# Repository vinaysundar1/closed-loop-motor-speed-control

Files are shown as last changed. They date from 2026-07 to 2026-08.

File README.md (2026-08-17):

# PID Motor Speed Controller

Closed-loop DC motor speed control using a quadrature encoder for feedback and a PID
algorithm to hold a target RPM, running on an Arduino Uno. Includes real-time serial
plotting and an OLED status display.

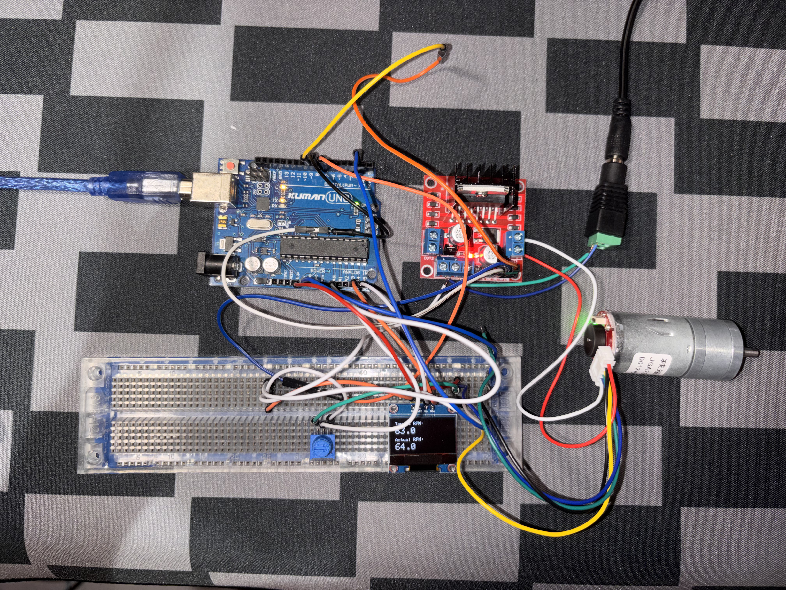
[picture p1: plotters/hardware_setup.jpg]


*Arduino Uno, L298N motor driver, GA25-370 encoder motor, potentiometer, and OLED display with a live RPM readout shown on screen.*

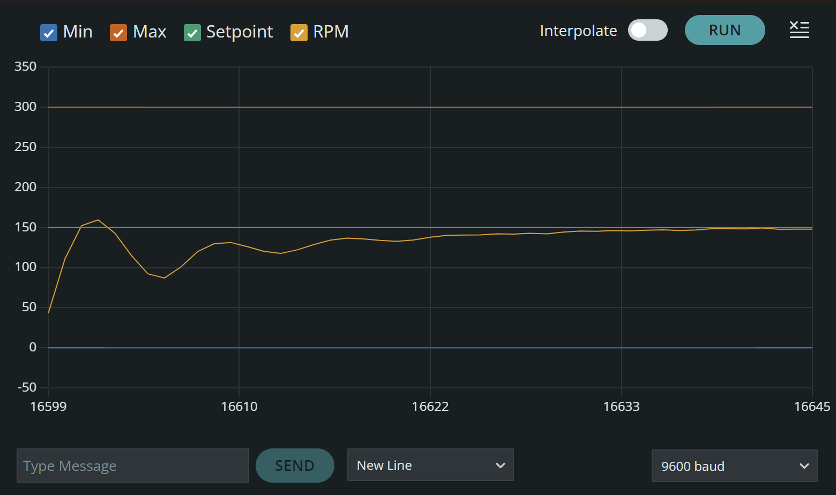
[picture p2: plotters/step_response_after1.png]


*Kp=0.5, Ki=0.5, Kd=0.08 — settles within one overshoot/undershoot cycle (~157 RPM
peak, ~90 RPM trough) and holds steady at setpoint.*

## Results

With a live, continuously-varying setpoint (driven by a potentiometer rather than a
fixed step), the controller tracks a ramping target with **one damped
overshoot/undershoot cycle** before settling, and holds within roughly **±2 RPM of
setpoint at steady state**.

## Hardware

| Component | Details |
|---|---|
| Arduino Uno | Microcontroller |
| L298N H-Bridge | Motor driver |
| DC motor with rotary encoder | GA25-370, 12V, 500 RPM nominal |
| 0.96" OLED display (SSD1306) | I2C status display |
| 10K potentiometer | Setpoint dial |
| 12V power supply or battery pack | Motor power |
| Breadboard + jumper wires | — |

## System Block Diagram

```mermaid
flowchart LR
    P[Potentiometer<br/>Setpoint Dial] -->|analog read,<br/>mapped 0-400 RPM| A[Setpoint]
    A --> B((Sum))
    F[Encoder Feedback] --> B
    B -->|error| C[PID Controller]
    C -->|PWM 0-255| D[Motor Driver / H-Bridge]
    D --> E[DC Gear Motor]
    E -->|shaft rotation| F
    E --> G[OLED Display]
    A --> G
```

## How It Works

1. **Speed measurement:** A hardware interrupt counts encoder pulses on every rising
   edge. Every 100 ms, the tick count is converted to RPM:
   `RPM = (ticks / PPR) * (60000 / interval_ms)`
2. **Noise filtering:** Raw RPM is smoothed with an exponential moving average (EMA)
   before being used anywhere else in the loop, since tick-count-based measurement
   over a short window is inherently noisy.
3. **PID calculation:** Standard proportional + integral + derivative sum, with:
   - A second EMA filter applied specifically to the derivative term (derivative
     amplifies noise more than any other term).
   - Conditional-integration anti-windup — the integral only accumulates when doing
     so wouldn't push the output past the PWM actuator limits (0–255).
4. **Actuation:** Final PID output is clamped to 0–255 (the PID math itself has no
   upper or lower bound, but `analogWrite` only accepts an 8-bit PWM duty cycle, so
   the raw sum has to be forced into the range the hardware can actually accept) and
   written via `analogWrite` to the motor driver's PWM input.

## Tuning Process

**Initial attempt** — naive PID with unfiltered RPM feedback:

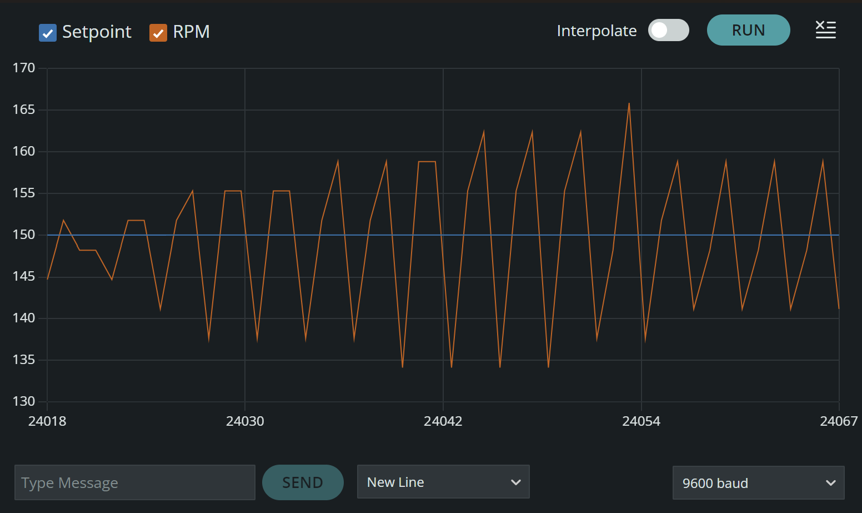
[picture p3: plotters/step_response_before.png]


*Kp=0.6, Ki=0.1, Kd=0.05 — oscillation amplitude grows over time rather than settling*

Diagnosis: the derivative term was amplifying tick-count measurement noise (division
by a small `dt` multiplies noise), and the integral anti-windup only clamped the
final value rather than preventing over-accumulation during saturation, both
contributing to a sustained/growing limit cycle.

**Fix:** added EMA filtering on the RPM measurement and on the derivative term, and
switched to conditional-integration anti-windup.

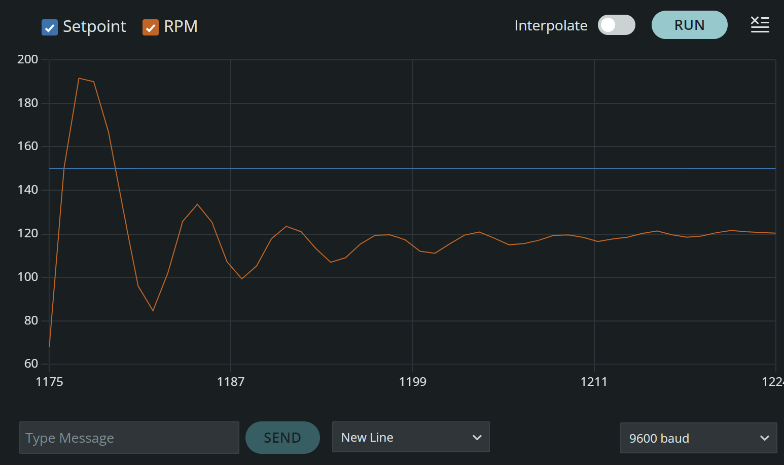
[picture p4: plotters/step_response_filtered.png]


*Kp=1.0, Ki=0.08, Kd=0.02 — clean damped response, but settles ~30 RPM below setpoint*

Diagnosis: proportional control alone cannot fully close steady-state error against
real motor friction/load, that gap can only be closed by the integral term, and Ki
was too small to close it in a reasonable time.

**Increased Ki to close the steady-state gap:**

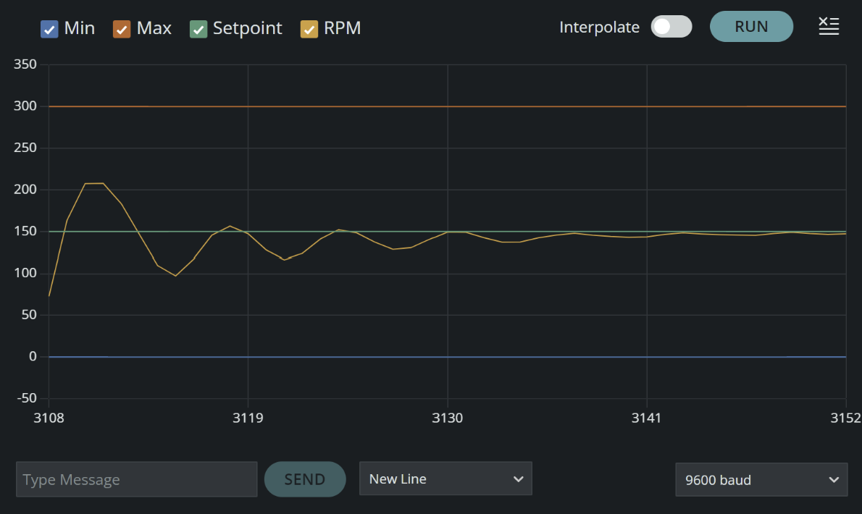
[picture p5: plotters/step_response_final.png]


*Kp=1.0, Ki=0.75, Kd=0.02 — closes the steady-state gap, but rings through roughly two
decaying overshoot/undershoot cycles before settling*

**Isolating the double-oscillation:** to find the cause, Kp was held fixed at 1.0
while Ki and Kd were varied independently across several tests (Ki: 0.75 → 0.35 → 0.5;
Kd: 0.02 → 0.2 → 0.08). The first overshoot peak stayed essentially unchanged
(~205–233 RPM) across every one of these combinations — strong evidence that Kp, not
Ki or Kd, was driving the size of that first overshoot, since neither term had moved
it despite multiple independent tests.

**Note on Ki tuning:** I also tested higher Ki values (up to 1.0) to see if faster settling was worth the tradeoff. Higher Ki consistently reduced settling time but increased overshoot (up to ~172 RPM vs. the original ~157 RPM), and increasing Kd alongside it didn't meaningfully reduce that overshoot. I kept Kp=0.5, Ki=0.5, Kd=0.08 as the final configuration since it produced the smallest overshoot/undershoot swings, which I prioritized over faster settling for this system.

**Final tune:** lowered Kp itself (1.0 → 0.6 → 0.5), keeping Ki=0.5 and Kd=0.08 fixed.
The first overshoot dropped sharply with each reduction (≈205 → 170 → 157 RPM), while
the undershoot depth stayed roughly constant (~90–100 RPM) regardless of Kp.



*Kp=0.5, Ki=0.5, Kd=0.08 — settles after one overshoot/undershoot cycle (~157 RPM peak,
~90 RPM trough), then a smooth, non-oscillatory approach to setpoint*

## Live Setpoint via Potentiometer

The initial tuning above used a fixed, hardcoded setpoint (150 RPM) for a clean,
repeatable step-response test. Once the gains were validated, the setpoint was
switched to a potentiometer read on an analog pin, mapped to a 0–400 RPM range, so
the target speed can be changed live by turning a knob.

A moving setpoint introduces failure modes a fixed step test doesn't expose:

- **Small electrical noise on the analog reading** caused the setpoint to
  flicker by a couple RPM every loop, which would look like a disturbance to the
  derivative term. Fixed with a deadband: the setpoint only updates if the
  new reading differs from the current one by more than 3 RPM.

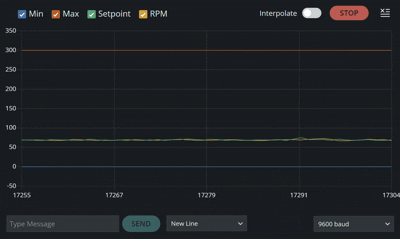
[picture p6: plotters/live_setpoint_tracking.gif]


*Kp=0.5, Ki=0.5, Kd=0.08 — RPM (orange) tracks a setpoint (green) jump, with one overshoot to one undershoot before settling and
holding steady-state tracking at the new target*

## Final PID Gains

| Gain | Value | Purpose |
|---|---|---|
| Kp | 0.5 | Primary response to instantaneous error; lowered from an initial 1.0 after isolating it as the driver of first-overshoot magnitude |
| Ki | 0.5 | Eliminates steady-state error from motor friction/load |
| Kd | 0.08 | Damps overshoot; raised from an initial 0.02 now that the derivative acts on a filtered signal |

## PCB Design

The breadboard prototype above was translated into a custom PCB in KiCad,
consolidating the Arduino, motor driver, and peripheral connections into a single
soldered board with defined connector headers.

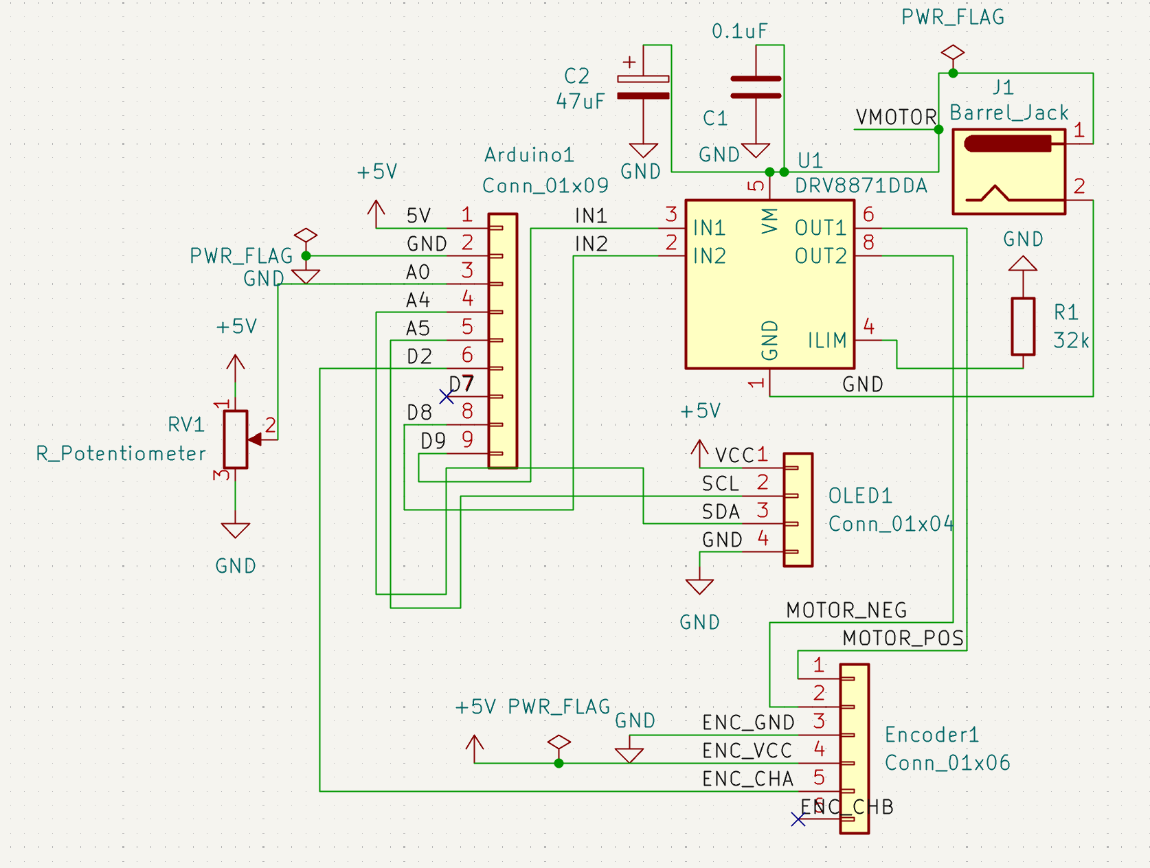
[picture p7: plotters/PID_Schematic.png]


*Full schematic — Arduino header, DRV8871 motor driver with support circuitry,
barrel jack power input, and connector headers for the encoder, OLED, and
potentiometer.*

### Driver Selection: DRV8871 over L298N

The original L298N module (used in the breadboard build above) was replaced with a
TI DRV8871 integrated H-bridge driver on the custom PCB. The DRV8871 integrates current limiting and thermal
protection directly, at the cost of requiring board-level component selection
(current-limit resistor, decoupling) rather than a plug-and-play module.

### Current-Limit (ILIM) Resistor

The DRV8871 sets its current limit via a resistor from ILIM to GND, per the
datasheet relationship ITRIP ≈ 64,000 / R_ILIM(Ω). The GA25-370's rated block/stall
current is 1.1A; a 32kΩ resistor was chosen to set a ~2A limit, giving roughly 2x
margin above the motor's normal stall current so the limit protects against
faults without nuisance-tripping during normal operation.

### Decoupling

A 0.1µF ceramic capacitor (high-frequency switching noise) and a 47µF electrolytic
capacitor (bulk current supply during motor transients) are placed across VM/GND,
matching TI's reference application circuit for this driver.

### Power Trace Sizing

Trace widths were calculated using KiCad's built-in IPC-2221 calculator:

| Net class | Current basis | Calculated minimum | Used |
|---|---|---|---|
| Power (VMOTOR, GND, motor outputs) | 2A (ILIM-protected worst case), 10°C rise | ~30.8 mil | 32 mil |
| Signal (I2C, control inputs, ILIM) | 1A reference, 10°C rise | ~12 mil | 12 mil |

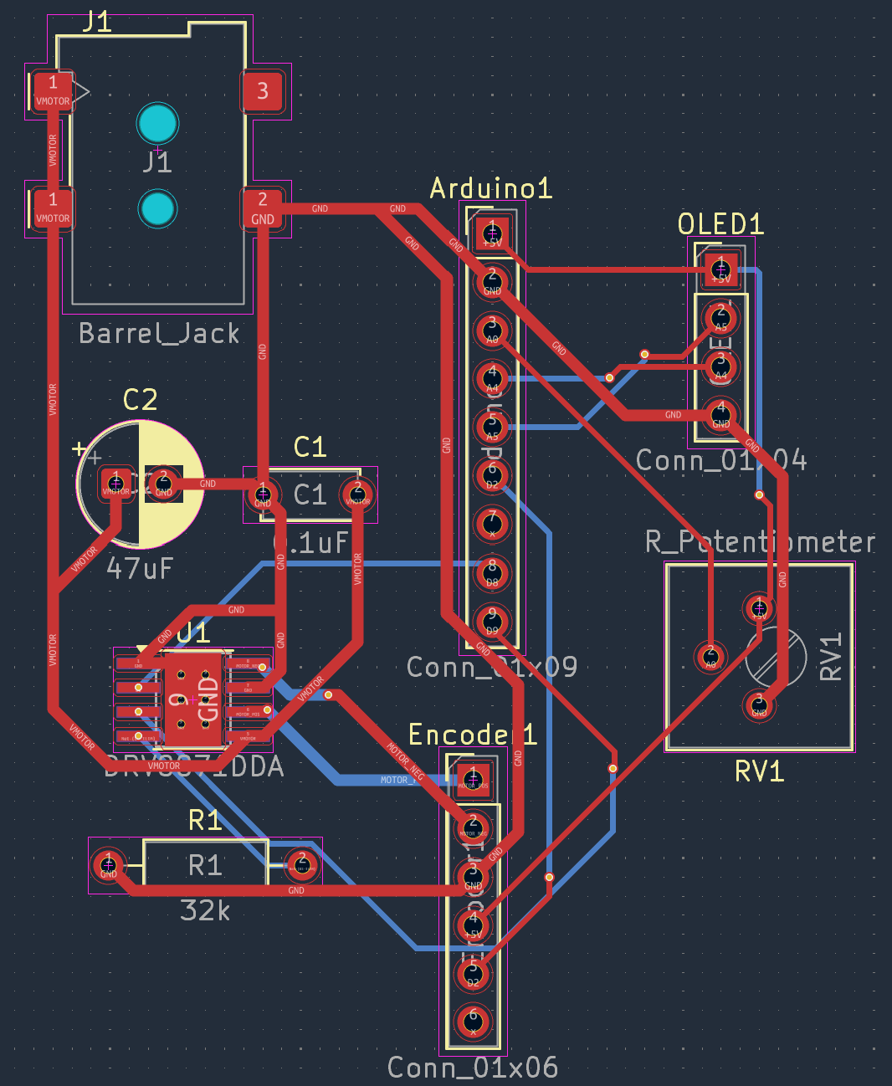
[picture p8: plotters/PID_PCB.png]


*Routed PCB layout — 0.8mm power traces (VMOTOR/GND/motor outputs), 0.3mm signal
traces, ground pour on the bottom layer with thermal vias under the driver IC.*

## Lessons Learned

- Sensor noise, not just gain values, can be the root cause of oscillation.
  Filtering the measurement is important in the tuning process.
- Anti-windup implementation matters: clamping the integral's final value is not the
  same as preventing it from over-accumulating in the first place.
- Empirical calibration (measuring encoder PPR directly) caught an incorrect
  assumption that a spec-sheet/datasheet number would have missed.
- Isolating one gain at a time was
  what actually revealed which gain caused which symptom. Multiple tests where Ki
  and Kd changed with no effect on the first overshoot were what pointed to Kp as
  the real cause, rather than guessing.

## Future Improvements

- Reset the integral term on large setpoint jumps, so accumulated history from the
  old target doesn't bleed into the transient response at a new one
- Quadrature (2-channel) decoding for direction sensing and 4x resolution
- Auto-tuning via relay/Ziegler-Nichols method triggered by a button press
- Using more precise motors and potentiometers to reduce error.

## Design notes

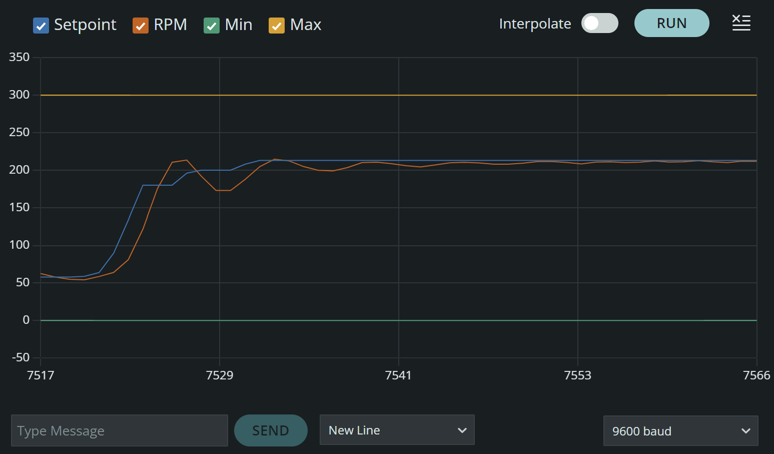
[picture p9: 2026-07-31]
plotters/live_setpoint_tracking.png

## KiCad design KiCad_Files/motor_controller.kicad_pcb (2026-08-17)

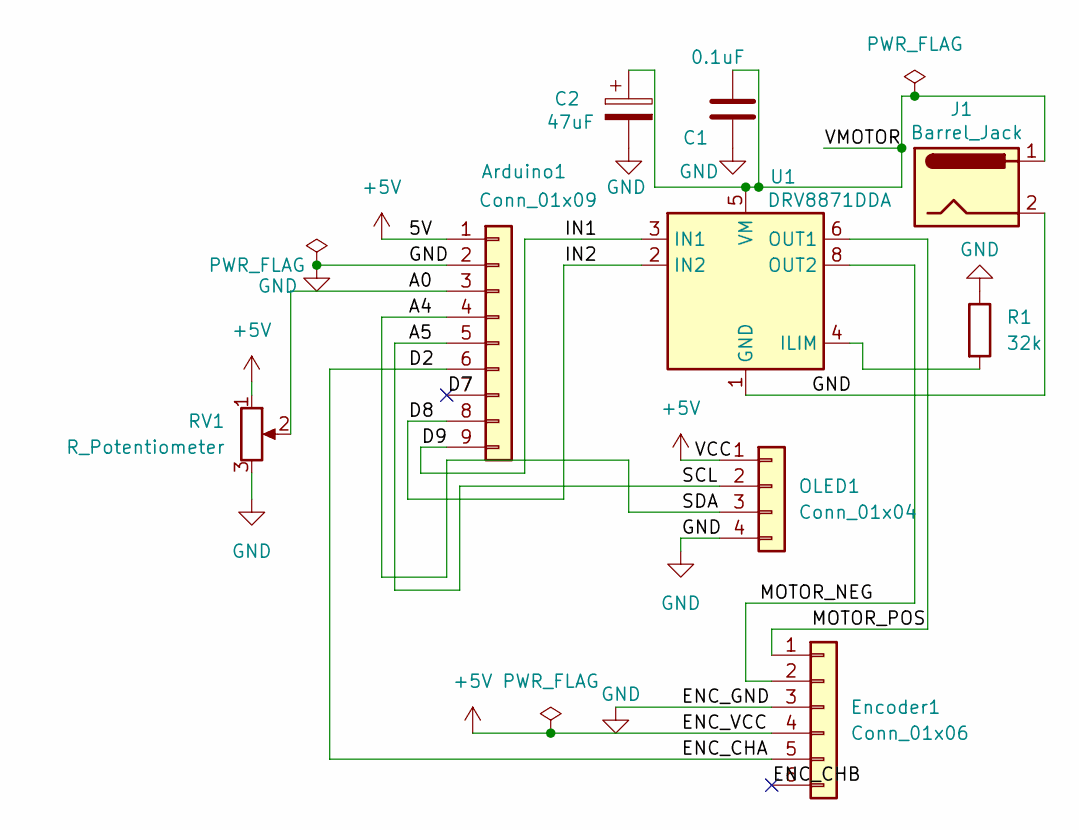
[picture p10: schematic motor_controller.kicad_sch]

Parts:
Arduino1: Conn_01x09; PinHeader_1x09_P2.54mm_Vertical
C1: 0.1uF; C_Disc_D5.0mm_W2.5mm_P5.00mm
C2: 47uF; CP_Radial_D6.3mm_P2.50mm
Encoder1: Conn_01x06; PinHeader_1x06_P2.54mm_Vertical
J1: Barrel_Jack; BarrelJack_Wuerth_694108106102_2.5x5.5mm
OLED1: Conn_01x04; PinHeader_1x04_P2.54mm_Vertical
R1: 32k; R_Axial_DIN0207_L6.3mm_D2.5mm_P10.16mm_Horizontal
RV1: R_Potentiometer; Potentiometer_Bourns_3386P_Vertical
U1: DRV8871DDA; Texas_HTSOP-8-1EP_3.9x4.9mm_P1.27mm_EP2.95x4.9mm_Mask2.4x3.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

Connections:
+5V: Arduino1.1, Encoder1.4, OLED1.1, RV1.1
/A0: Arduino1.3, RV1.2
/A4: Arduino1.4, OLED1.3
/A5: Arduino1.5, OLED1.2
/D2: Arduino1.6, Encoder1.5
/D7: Arduino1.7
/D8: Arduino1.8, U1.2 (IN2)
/D9: Arduino1.9, U1.3 (IN1)
/ENC_CHB: Encoder1.6
/MOTOR_NEG: Encoder1.2, U1.8 (OUT2)
/MOTOR_POS: Encoder1.1, U1.6 (OUT1)
/VMOTOR: C1.2, C2.1, J1.1, U1.5 (VM)
GND: Arduino1.2, C1.1, C2.2, Encoder1.3, J1.2, OLED1.4, R1.1, RV1.3, U1.1 (GND), U1.7 (GND), U1.9 (GND)
unnamed: R1.2, U1.4 (ILIM)

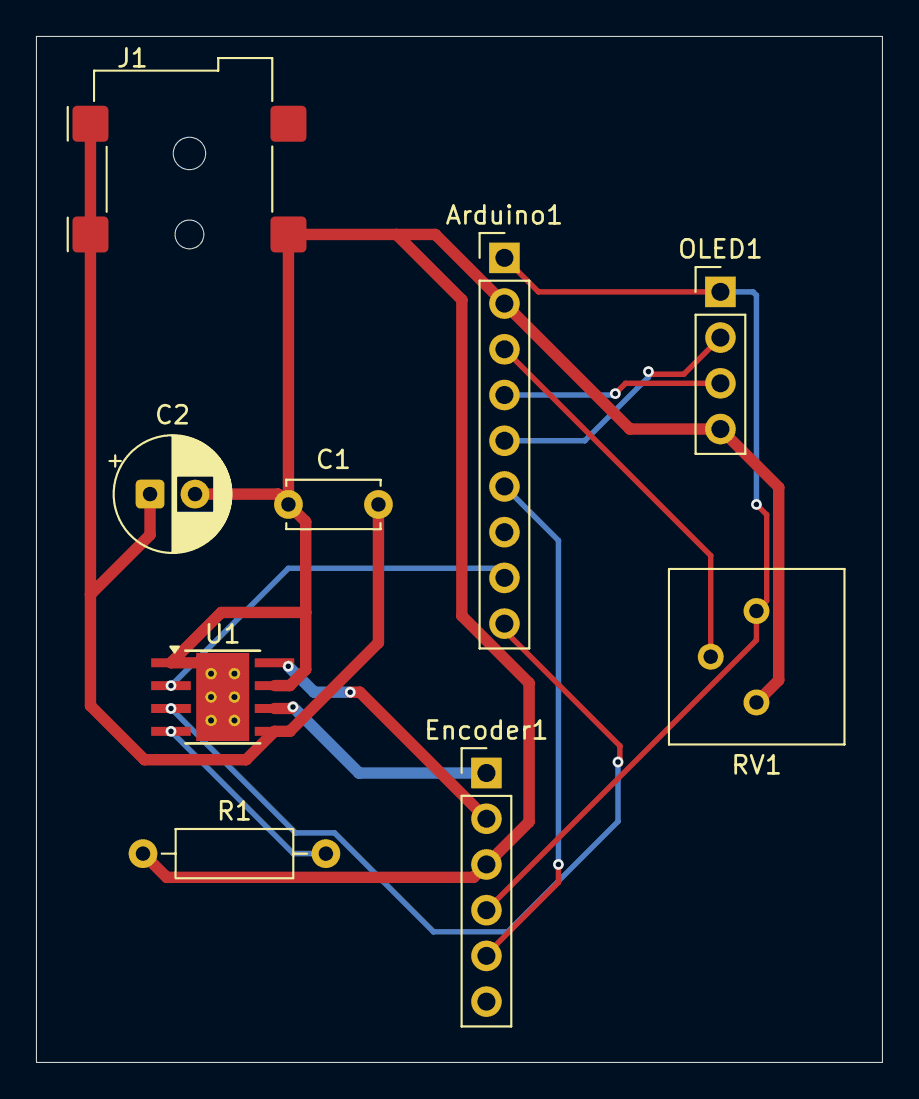
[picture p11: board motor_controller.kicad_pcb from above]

Board: 2 copper layers, 47.0 x 57.0 mm, 9 parts (0 on the bottom side), 12 nets.

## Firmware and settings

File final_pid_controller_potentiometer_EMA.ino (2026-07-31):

#include <Wire.h>
#include <Adafruit_GFX.h>
#include <Adafruit_SSD1306.h>

// --- OLED SETTINGS ---
#define SCREEN_WIDTH 128
#define SCREEN_HEIGHT 64
#define OLED_RESET -1
Adafruit_SSD1306 display(SCREEN_WIDTH, SCREEN_HEIGHT, &Wire, OLED_RESET);

// --- PIN DEFINITIONS ---
const int ENB = 9;
const int IN3 = 8;
const int IN4 = 7;
const int encoderPin = 2;
const int potPin = A0;

// --- MOTOR SPECIFICATIONS ---
const float PPR = 170.0;

// --- PID VARIABLES ---
double kp = 0.5;
double ki = 0.5;
double kd = 0.08;

double setpoint = 0.0;
double currentRPM = 0.0;       
double rawRPM = 0.0;           
double motorOutput = 0.0;

double error = 0.0;
double previousError = 0.0;
double integral = 0.0;
double filteredDerivative = 0.0;

// --- FILTER SETTINGS ---
const double RPM_FILTER_ALPHA = 0.35;   
const double D_FILTER_ALPHA   = 0.2;    

// --- TIME & COUNTING VARIABLES ---
volatile long encoderTicks = 0;
long previousMillis = 0;
int interval = 100;

void setup() {
  Serial.begin(9600);

  if (!display.begin(SSD1306_SWITCHCAPVCC, 0x3C)) {
    Serial.println("SSD1306 allocation failed");
    for (;;);
  }
  display.clearDisplay();
  display.setTextColor(WHITE);

  pinMode(ENB, OUTPUT);
  pinMode(IN3, OUTPUT);
  pinMode(IN4, OUTPUT);
  pinMode(encoderPin, INPUT_PULLUP);

  digitalWrite(IN3, HIGH);
  digitalWrite(IN4, LOW);

  attachInterrupt(digitalPinToInterrupt(encoderPin), countTicks, RISING);
}

void loop() {

  long currentMillis = millis();

  // Read potentiometer and map to an RPM range (0 to 400 RPM)
  int potValue = analogRead(potPin);
  double newSetpoint =  map(potValue, 0, 1023, 0, 400);
  
  // Deadband filter to prevent tiny electrical potentiometer flickers from causing derivative kicks
  if (abs(newSetpoint - setpoint) > 3.0) {
    setpoint = newSetpoint;
  }

  if (currentMillis - previousMillis >= interval) {
    previousMillis = currentMillis;

    // 1. Calculate RAW RPM from tick count
    noInterrupts();
    long ticks = encoderTicks;
    encoderTicks = 0;
    interrupts();
    rawRPM = ((float)ticks / PPR) * (60000.0 / interval);

    // 1b. Low-pass filter the RPM reading
    currentRPM = RPM_FILTER_ALPHA * rawRPM + (1.0 - RPM_FILTER_ALPHA) * currentRPM;

    // 2. PID Calculations
    error = setpoint - currentRPM;
    double dt = interval / 1000.0;

    double p_term = kp * error;

    double raw_derivative = (error - previousError) / dt;
    previousError = error;

    filteredDerivative = D_FILTER_ALPHA * raw_derivative + (1.0 - D_FILTER_ALPHA) * filteredDerivative;
    double d_term = kd * filteredDerivative;

    double tentativeOutput = p_term + integral + d_term;

    bool willSaturateHigh = (tentativeOutput > 255) && (error > 0);
    bool willSaturateLow  = (tentativeOutput < 0)   && (error < 0);
    if (!willSaturateHigh && !willSaturateLow) {
      integral += ki * error * dt;
    }
    
    if (integral > 255) integral = 255;
    if (integral < -255) integral = -255;

    motorOutput = p_term + integral + d_term;
    if (motorOutput > 255) motorOutput = 255;
    if (motorOutput < 0) motorOutput = 0;

    // 5. Drive the Motor
    analogWrite(ENB, motorOutput);

    // 6. Serial Plotter output
    Serial.print("Min:0,");       
    Serial.print("Max:300,");     
    Serial.print("Setpoint:");
    Serial.print(setpoint);
    Serial.print(", RPM:");
    Serial.println(currentRPM);

    // 7. OLED
    updateOLED();
  }
}

void updateOLED() {
  display.clearDisplay();

  display.setTextSize(1);
  display.setCursor(0, 0);
  display.print("Target RPM: ");
  display.setTextSize(2);
  display.setCursor(0, 12);
  display.print(setpoint, 1);

  display.setTextSize(1);
  display.setCursor(0, 36);
  display.print("Actual RPM: ");
  display.setTextSize(2);
  display.setCursor(0, 48);
  display.print(currentRPM, 1);

  display.display();
}

void countTicks() {
  encoderTicks++;
}

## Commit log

2026-07-31 Revise README for PID Motor Speed Controller
    Updated README to provide detailed project description, results, hardware specifications, system block diagram, and tuning process for PID motor speed controller.
2026-07-31 Refine README with clarifications and updates
    Updated README to clarify the PID actuation process, improve measurement details, and refine lessons learned.
2026-07-31 final iteration filtered
2026-07-31 Refine README by removing gearbox ratio details
    Removed unnecessary explanation about gearbox ratios and updated tuning process notes.
2026-07-31 Update README with PID controller tuning details
    Added tuning parameters for PID controller performance.
2026-07-31 Update README with Ki tuning insights
    Added a note on Ki tuning and final configuration for PID parameters.
2026-08-17 Document PCB design and driver selection details
    Added detailed PCB design information, including driver selection, current-limit resistor, decoupling, and power trace sizing.
2026-08-17 Remove encoder calibration and refine tuning process
    Removed encoder calibration section and updated tuning process details.
2026-09-12 Revise README with updated hardware and PCB details
    Updated README to reflect changes in hardware components and PCB design.
2026-10-11 Remove driver selection section
    Removed section
